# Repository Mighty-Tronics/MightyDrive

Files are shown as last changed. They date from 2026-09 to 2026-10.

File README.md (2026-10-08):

# MT Drive — Four-Channel PWM Pump Interface

**Certified Open Source Hardware — [OSHWA LU000003](https://certification.oshwa.org/lu000003.html)**

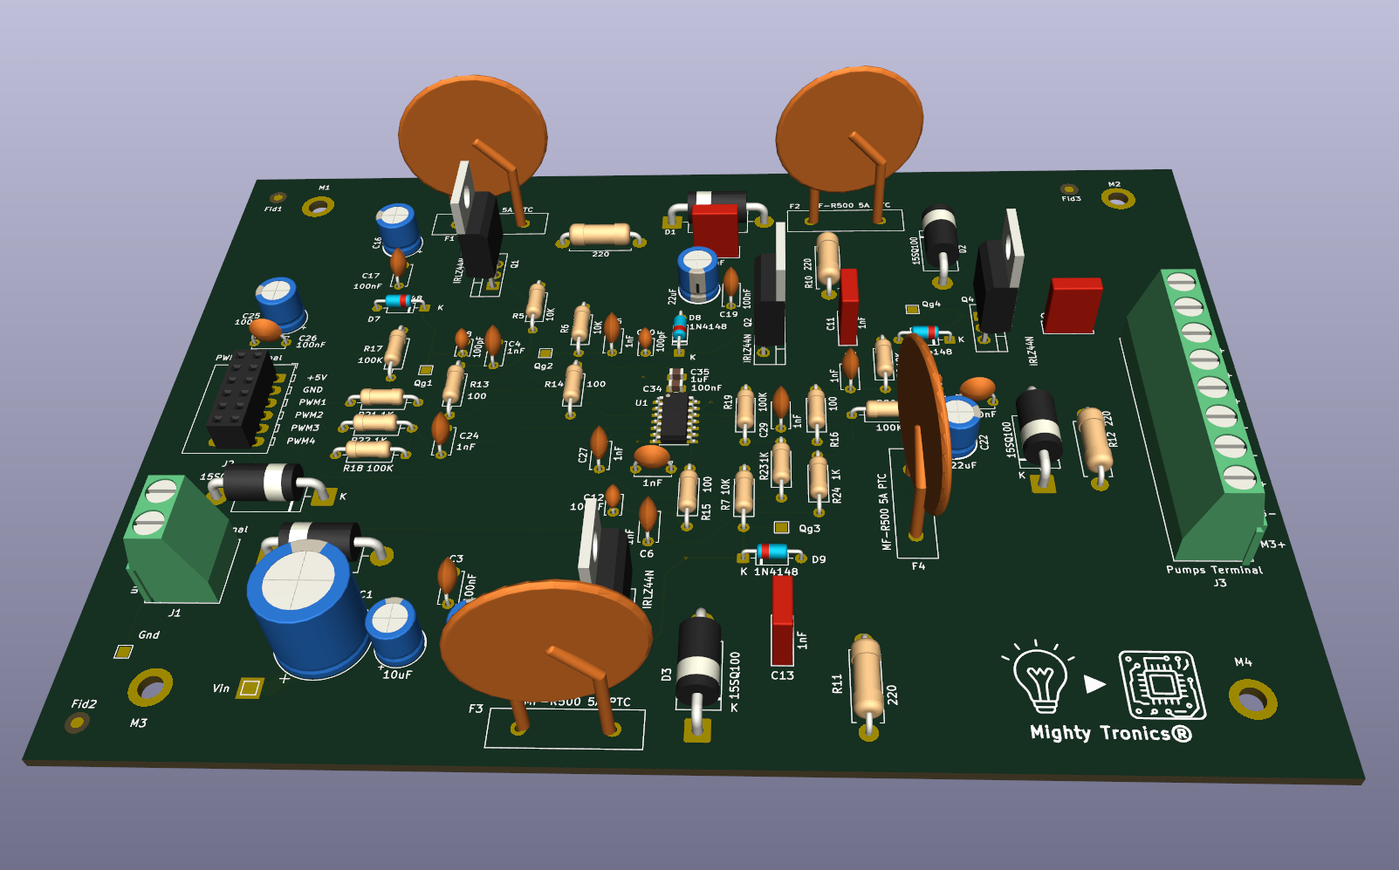
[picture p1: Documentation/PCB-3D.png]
PCB 3D


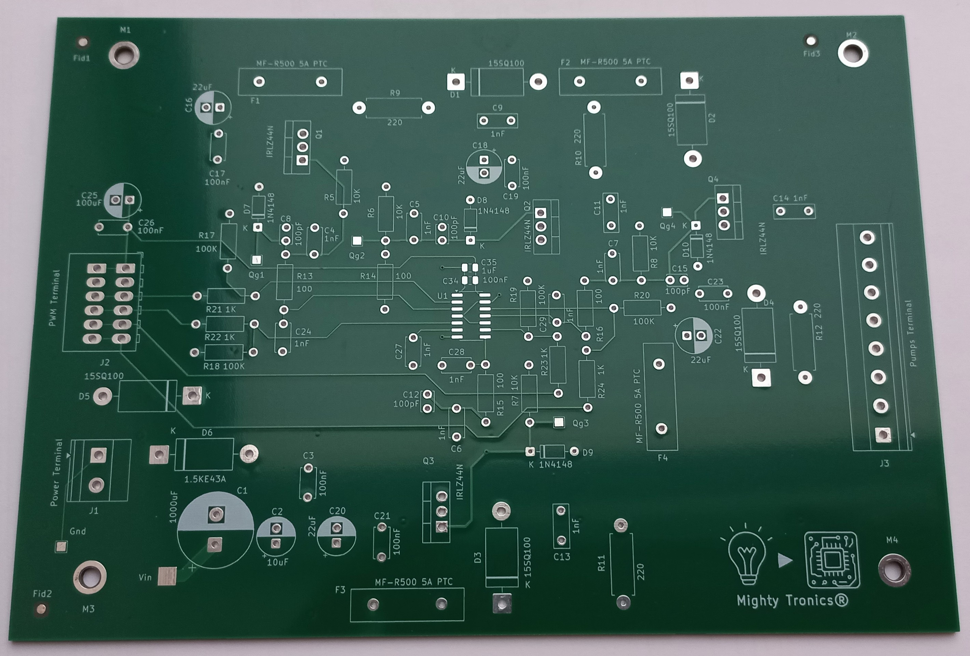
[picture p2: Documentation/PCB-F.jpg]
PCB-photo1


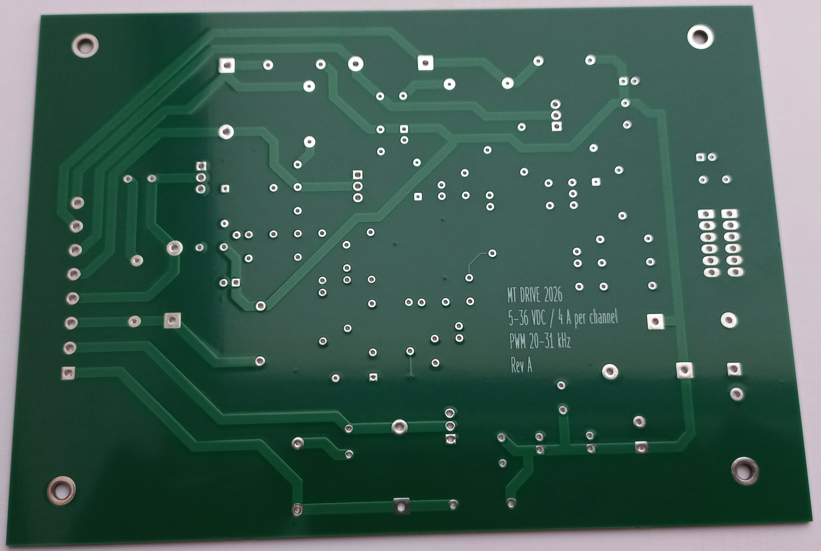
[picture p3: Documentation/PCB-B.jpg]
PCB-photo2


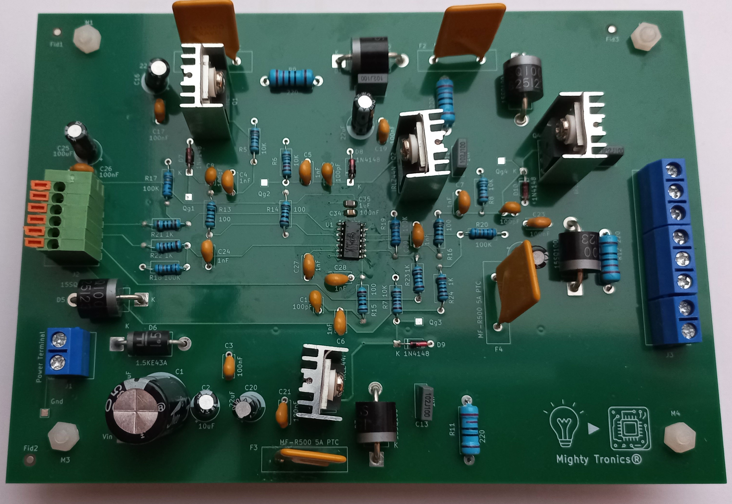
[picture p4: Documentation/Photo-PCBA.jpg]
PCBA-photo


MT Drive is an open-hardware power interface for controlling up to four brushed DC pumps or comparable inductive DC loads from an external microcontroller.

Each channel accepts an independent PWM command and switches the load through a protected low-side MOSFET stage. The microcontroller, firmware, regulated +5 V logic supply, motor supply and pumps remain external to the board.

> **Hardware status:** prototype revision V2.0, manufactured by PCBWay and under qualification.  
> **Published electrical rating:** 2 A continuous per channel, 8 A continuous total.  
> **Extended operation:** up to 3 A per channel may be characterized, but is not guaranteed for this hardware revision.

## Main specifications

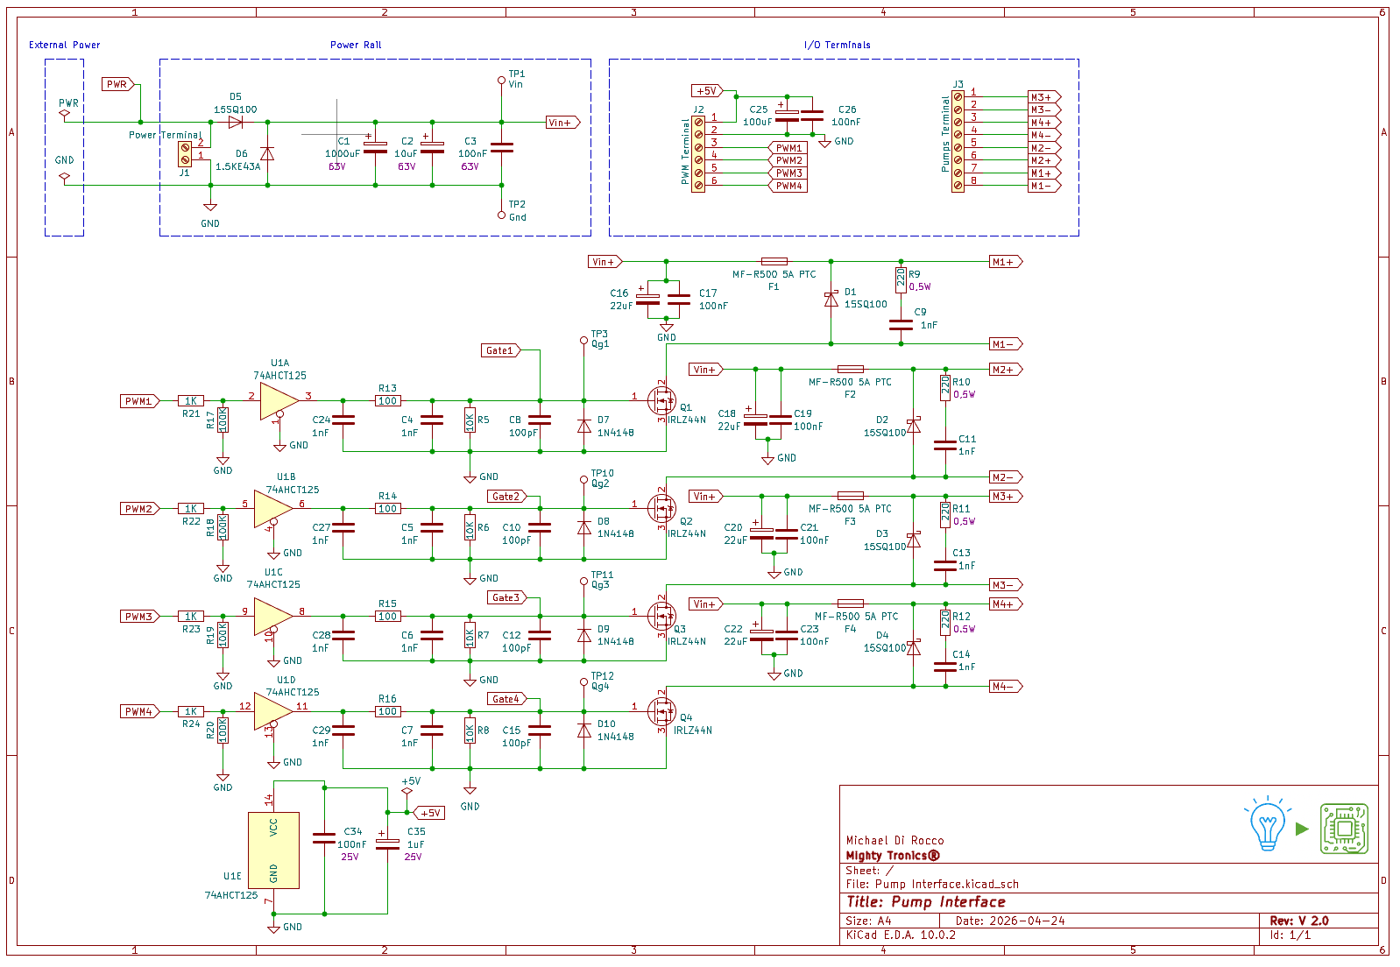
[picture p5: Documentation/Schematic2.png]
Schematic


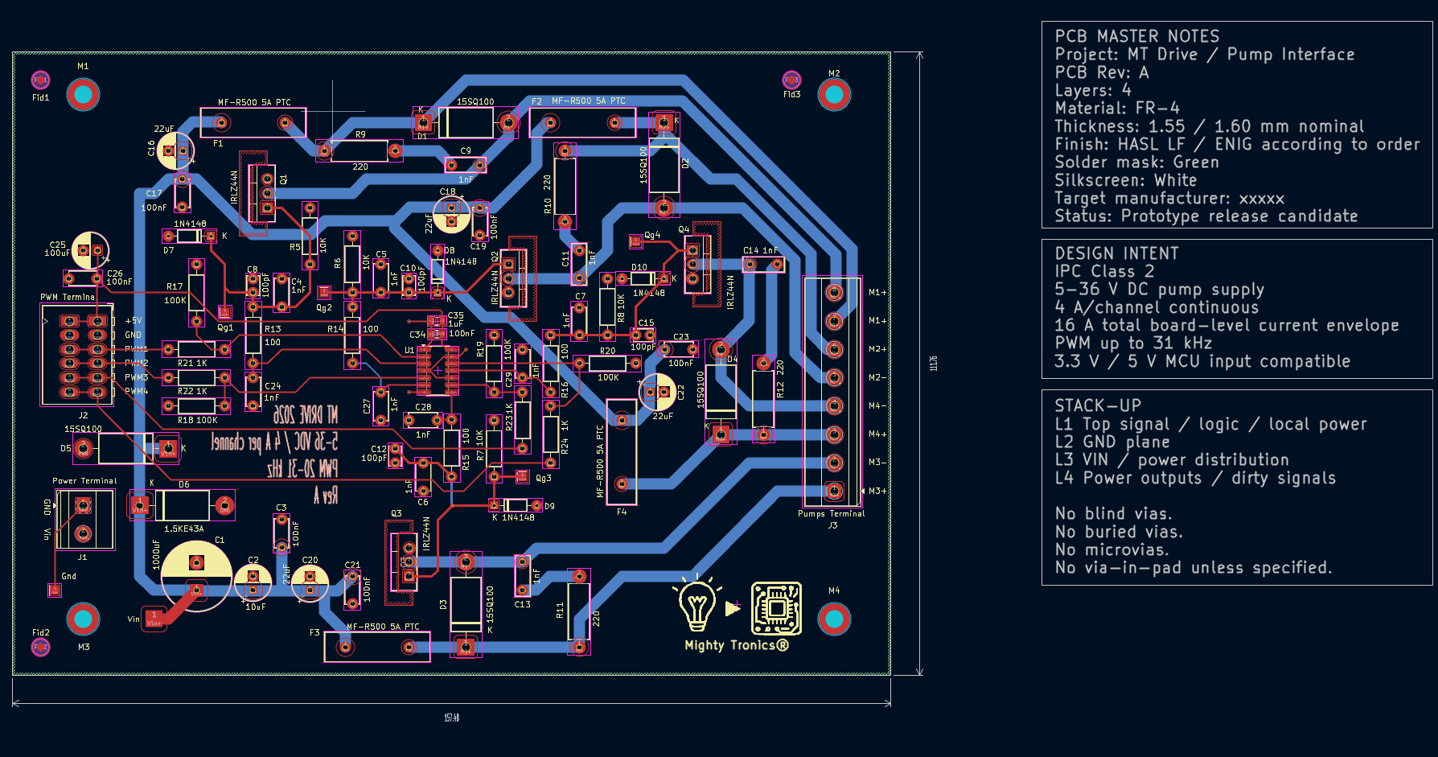
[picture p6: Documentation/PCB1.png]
PCB


| Characteristic | Published specification |
| --- | --- |
| Number of channels | 4 independent outputs |
| Motor supply | 5–36 V DC, externally supplied |
| Continuous current | 2 A maximum per channel |
| Aggregate continuous current | 8 A maximum |
| Extended characterization | Up to 3 A per channel / 12 A total, not guaranteed |
| PWM frequency | 31.5 kHz nominal |
| PWM input levels | 3.3 V or 5 V logic |
| Logic supply | Regulated +5 V external supply |
| Switching topology | N-channel MOSFET, low-side switching |
| Intended ambient range | −10 °C to +50 °C |
| Galvanic isolation | None; logic and motor power use a common ground |
| Hardware reference | Pump Interface schematic V2.0, dated 24 April 2026 |

At 36 V and the published current rating, the board can deliver up to 72 W per load and 288 W to four loads. These values are load power, not PCB dissipation.

## Functional operation

### Power entry

The motor supply enters through `J1`:

- `PWR`: positive motor supply, 5–36 V DC;
- `GND`: common power and logic reference.

The common input stage includes:

- `D5` 15SQ100 series Schottky diode for reverse-polarity protection;
- `D6` 1.5KE43A TVS diode for supply transient suppression;
- `C1` 1000 µF, `C2` 10 µF and `C3` 100 nF for rail decoupling;
- `TP1` and `TP2` for protected `Vin+` and ground measurements.

### PWM command path

Each PWM input passes through a 1 kΩ series resistor and a 100 kΩ pull-down before entering one section of the `74AHCT125` buffer. The buffer is powered from +5 V and adapts a 3.3 V or 5 V controller signal to the 5 V MOSFET gate-control network.

The `74AHCT125` has been bench-tested for this level-adaptation function. It carries gate-drive current only and does not determine the motor-current rating.

The four buffer outputs are permanently enabled because their active-low `/OE` inputs are tied to ground. Gate pull-down resistors keep the MOSFETs off when the controller is disconnected or its outputs are high-impedance.

### Load switching

When a PWM command is high, the corresponding `IRLZ44N` MOSFET turns on. Current flows from `Vin+`, through the channel PTC, through the external load connected between `Mx+` and `Mx−`, and through the MOSFET to ground.

When the MOSFET turns off, the channel flyback diode maintains a local path for the inductive load current. A 22 Ω + 1 nF series RC snubber damps high-frequency ringing across each motor output.

## Connections

### J2 — Logic and PWM

| Pin | Signal | Description |
| ---: | --- | --- |
| 1 | +5 V | External regulated logic supply |
| 2 | GND | Common controller and power-stage reference |
| 3 | PWM1 | Channel 1 command |
| 4 | PWM2 | Channel 2 command |
| 5 | PWM3 | Channel 3 command |
| 6 | PWM4 | Channel 4 command |

### J3 — Pump outputs

| Pin | Signal | Pin | Signal |
| ---: | --- | ---: | --- |
| 1 | M3+ | 2 | M3− |
| 3 | M4+ | 4 | M4− |
| 5 | M2+ | 6 | M2− |
| 7 | M1+ | 8 | M1− |

### Test points

| Test point | Signal |
| --- | --- |
| TP1 | Protected motor rail `Vin+` |
| TP2 | GND |
| TP3 | Channel 1 gate, `Qg1` |
| TP10 | Channel 2 gate, `Qg2` |
| TP11 | Channel 3 gate, `Qg3` |
| TP12 | Channel 4 gate, `Qg4` |

## Protection and reliability architecture

Each channel contains:

- one `MF-R500` resettable PTC in the positive load feed;
- one `15SQ100` flyback diode;
- local 22 µF + 100 nF supply decoupling;
- one 22 Ω / 0.5 W + 1 nF series RC snubber;
- a 10 kΩ MOSFET gate pull-down;
- a 1N4148 gate clamp and gate-conditioning capacitors.

The protections have different roles and do not replace one another. The PTC limits sustained fault energy but is not a precision current limiter. The flyback diode controls inductive current, the snubber damps local ringing, and the TVS limits disturbances reaching the common supply rail.

The 55 V `IRLZ44N` has 19 V of absolute drain-voltage headroom at a 36 V supply. The internal qualification target is a repetitive `VDS` peak no greater than 45 V under the published load, worst switching condition and longest intended motor cable.

## Current and thermal basis

The 2 A/channel rating is based on the complete current path rather than on the headline rating of a single semiconductor.

- Four channels at 2 A give an 8 A continuous common-path current.
- Using the 15SQ100 maximum forward-voltage screening value of 0.82 V gives a conservative `D5` loss bound of 6.56 W at 8 A. Actual forward drop and case temperature must be measured.
- The `MF-R500` hold current falls with ambient temperature; 2 A retains useful margin up to the declared +50 °C design ambient.
- MOSFET conduction and switching losses are verified at 31.5 kHz from measured gate and drain waveforms.
- Power-component case temperatures are checked against the 90 °C internal qualification target.

Operation above 2 A per channel, up to 3 A, is an engineering-characterization region only. It depends on duty cycle, pump start and stall current, ambient temperature, airflow, wiring, connector losses and simultaneous channel loading.

## Integration requirements

1. Connect the controller ground to `J2 GND` before applying PWM signals.
2. Apply a regulated +5 V supply to `J2`; the board does not generate this voltage.
3. Use a current-limited motor supply for first power-up.
4. Size the supply, connectors and cable loop for 8 A continuous total current plus pump start-current transients.
5. Keep PWM and ground wiring short and route motor cables away from sensitive logic wiring.
6. Do not exceed 2 A continuous on any channel or 8 A continuous in total within the published specification.
7. Verify each pump's start and stall current before qualification in the final system.

The board does not regulate motor voltage, provide active electronic current limiting or provide galvanic isolation. It is a component for integration, not a complete protected end product.

## Validation plan

The production-representative board is verified using the following sequence:

1. Inspect component orientation, solder joints and unpowered resistance paths.
2. Apply logic power only and verify all four PWM inputs, buffer outputs and MOSFET gates at 3.3 V and 5 V input levels.
3. Test each channel with a current-limited resistive load before connecting pumps.
4. Verify operation at 31.5 kHz and 10%, 50% and 90% duty cycle.
5. Qualify one channel at 36 V / 2 A over the full duty-cycle range.
6. Qualify four simultaneous channels at 36 V / 2 A per channel after thermal stabilization.
7. Measure MOSFET `VDS` peaks and ringing with the longest intended cable.
8. Record start, stall, reverse-polarity, endurance and high-ambient behaviour.
9. Characterize operation progressively above 2 A and up to 3 A separately, without changing the published rating.
10. Complete EMC pre-compliance tests using the final PCB, pumps, supply and cabling.

No CE conformity claim is made solely from this prototype or this repository. Regulatory assessment applies to the final integrated product and its intended use.

## Repository contents

The repository separates editable design sources from documentation and generated manufacturing outputs:

| Location | Contents |
| --- | --- |
| `Documentation/` | BOM in ODS and CSV formats; schematic images; drill maps; Gerber and Excellon manufacturing files in a ZIP archive; Master Drawing; functional and engineering notes. |
| `Kicad_Files/` | Native KiCad files for viewing and editing the schematic and PCB. |
| `README.md` | Project overview, specifications, integration guidance and certification information. |
| `LICENSE.md` | Project licence information. |

The native KiCad files are the authoritative editable design sources. Rendered schematics, PDFs and manufacturing files are provided for convenient review and production, but do not replace the native source files.

Every hardware release must identify its PCB revision or release date and match it to an immutable repository tag, BOM, schematic, layout and validation evidence.

[Master Drawing — Pump Interface, Rev A](https://github.com/Mighty-Tronics/MightyDrive/blob/main/Documentation/Pump_Interface_MasterDrawing_Rev_A.pdf)

## OSHWA certification

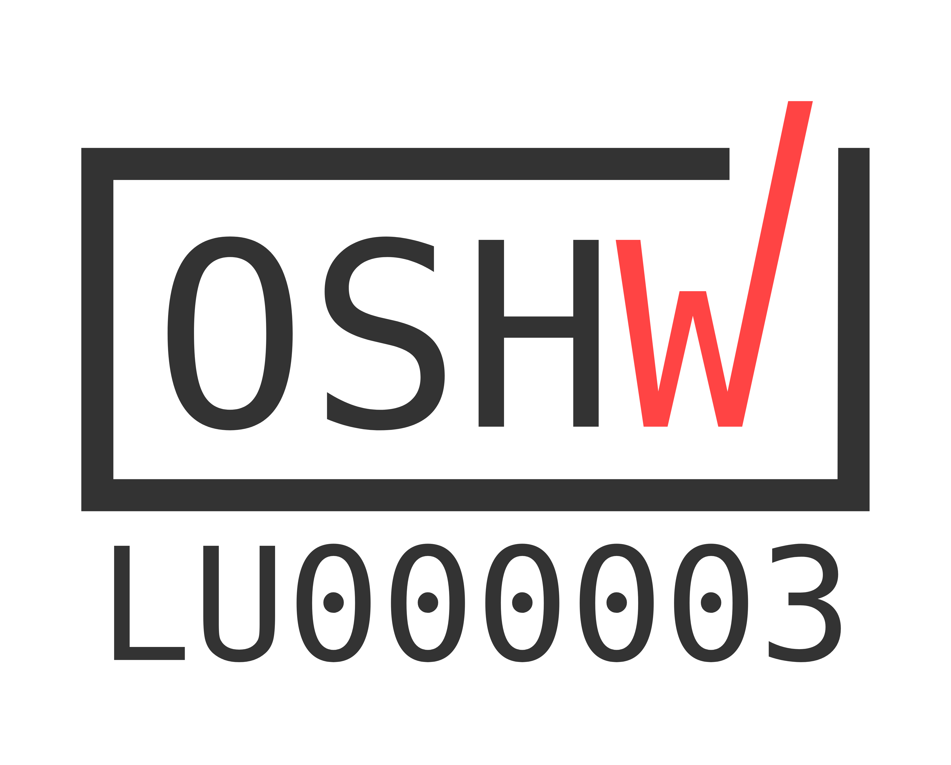
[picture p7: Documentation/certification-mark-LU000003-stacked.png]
OSHWA Certified Open Source Hardware — LU000003 (https://certification.oshwa.org/lu000003.html)


**MT Drive is certified open source hardware under the Open Source Hardware Association (OSHWA) certification program.** The project is registered as **Mighty Drive** in the official OSHWA directory.

| Certification information | Details |
| --- | --- |
| Registered project name | Mighty Drive |
| Unique identifier (UID) | **LU000003** |
| Certification date | **3 October 2026** |
| Official registration | [OSHWA project record — LU000003](https://certification.oshwa.org/lu000003.html) |

OSHWA certification identifies projects that comply with the [Open Source Hardware Definition](https://oshwa.org/definition/). The editable design files and project documentation are published so that users can study, modify, build and distribute the design under the applicable licence.

**Certification scope:** OSHWA certification concerns open-source hardware compliance. It does not certify electrical performance, product safety or CE/EMC conformity. Hardware qualification and final-system regulatory assessment are addressed separately in the validation plan above.

The certification mark and UID refer to the project covered by the official registration. Use of the mark follows the [OSHWA Certification Mark Usage Guidelines](https://certification.oshwa.org/mark-usage.html).

## License

The hardware design and original project documentation are released under the **CERN Open Hardware Licence Version 2 — Strongly Reciprocal (`CERN-OHL-S-2.0`)**. See [`LICENSE.md`](LICENSE.md) and the [official CERN-OHL-S v2 licence text](https://ohwr.org/cern_ohl_s_v2.txt) for the applicable terms.

| Project material | License |
| --- | --- |
| Hardware design, schematic, PCB, fabrication files and BOM | CERN-OHL-S-2.0 |
| Original project documentation | CERN-OHL-S-2.0 |
| Software or firmware | None included in this release |

Third-party data sheets and manufacturer files retain their owners' respective rights and are not relicensed by their inclusion or citation. The OSHWA certification mark remains subject to OSHWA's own usage terms.

## Documentation

The detailed functional description, engineering calculations, component-level implementation and qualification criteria are provided in the project documentation under [`Documentation/`](Documentation/).

## Maintainer

[info@mightytronics.eu](mailto:info@mightytronics.eu)

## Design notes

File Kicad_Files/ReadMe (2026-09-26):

This folder include all schematics and pcb files done by Kicad 10.

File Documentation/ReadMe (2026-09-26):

This folder include all necessary documents to understand the projects:
_PGN and PDF files of schematics and PCB
_Master Drawing
_BOM list
_Engineering doc

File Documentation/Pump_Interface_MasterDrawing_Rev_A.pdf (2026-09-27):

# PUMP INTERFACE MASTER

# DRAWING – REV A

Michael

info@mightytronics.eu

Version & Revision

V 1.0

## MIGHTY TRONICS®

Project name: Pump Interface | Page 1 / 12
Version : 1.0

## LIST OF CONTENTS

## 1. HISTORY OF VERSION

Date | Version | Amendments
27-09-2026 | V1.0 | Document initiation

## 2. IDENTIFICATION AND DRAWING AUTHORITY

Item | Definition
Board / design | MT Drive — Pump Interface; four-layer rigid PCB
Fabrication package | Pump Interface-GerberExcellon_Y2 (JLCPCB product detail screenshot)
Manufacturer / lot | JLCPCB / 5 individual PCBs; one design
Source CAD | Pump Interface.kicad_pcb; native board file not supplied for this revision
Data precedence | Approved fabrication data and order settings govern geometry and process. Resolve any conflict with this drawing before fabrication. Do not scale the illustration.
Drawing status | Documentation draft for the existing prototype order; not released as a new fabrication authority

## 3. BOARD OUTLINE AND REFERENCE VIEW

Property | Specified value / source
Overall dimensions | 157.5 × 111.8 mm, as displayed in the JLCPCB order detail
Outline tolerance | ±0.2 mm (Regular), as selected in the JLCPCB order
Board thickness | 1.6 mm nominal; manufacturing tolerance per JLCPCB order/process
Board construction | Four-layer FR-4, material option TG135; dielectric stack-up not separately specified
Mounting holes | 4 × Ø3.20 mm NPTH, subject to Excellon and Edge.Cuts verification

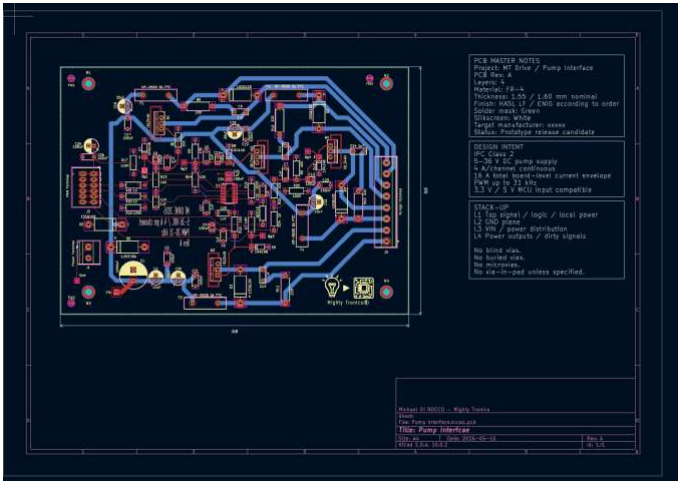
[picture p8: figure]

Figure 1 - Supplied KiCad drawing screenshot, shown for reference only. Some embedded notes reflect earlier assumptions; the verified order settings in Sections 3 and 4 take precedence. The drawing image must not be used to derive dimensions.

## 4. LAYER STRUCTURE AND ORDERED FABRICATION OPTIONS

Layer / feature | Function and order setting
L1 / F.Cu | Top copper, nominal 1 oz (approximately 35 µm copper weight equivalent); signals, logic and local power
L2 / In1.Cu | Inner copper, nominal 2 oz (approximately 70 µm); GND plane
L3 / In2.Cu | Inner copper, nominal 2 oz (approximately 70 µm); VIN / power distribution
L4 / B.Cu | Bottom copper, nominal 1 oz (approximately 35 µm); power outputs and other routed nets
Layer sequence / dielectrics | Four layers ordered; “No requirement” for a specified stack-up. Confirm actual dielectric construction with the manufacturer if controlled impedance or dielectric spacing is required.
Surface finish | HASL with lead (SnPb), as ordered. Do not label this finish lead-free.
Solder mask / legend | Green solder mask; white ink-jet silkscreen
Via treatment | Covered vias (“Bouché” in the translated order detail); confirm the exact JLCPCB process meaning from production data if plugging/filling is required
Electrical test | Full flying-probe electrical test
Appearance quality | JLCPCB “IPC Class 2 Standard” option; not independent evidence of full IPC-6012 certification
Other selections | No castellations, blind holes, edge plating, countersinks, gold fingers, UL marking or inspection report ordered

Copper weights describe the manufacturer order selections. The approximate 35/70 µm conversions are nominal copper-weight equivalents, not measured final thicknesses or guaranteed finished copper tolerances. External plating may affect local finished thickness.

## 5. DRILL SCHEDULE

Tool | Hole type | Nominal Ø | Count | Plated
T1 | PTH | 0.40 | 4 | Yes
T2 | PTH | 0.65 | 8 | Yes
T3 | PTH | 0.80 | 84 | Yes
T4 | PTH | 0.90 | 12 | Yes
T5 | PTH | 1.00 | 10 | Yes
T6 | PTH | 1.20 | 12 | Yes
T7 | PTH | 1.25 | 2 | Yes
T8 | PTH | 1.30 | 12 | Yes
T9 | PTH | 1.40 | 20 | Yes
T10 | NPTH | 3.20 | 4 | No

Schedule total: 164 plated through holes and 4 non-plated through holes, 168 holes overall. Verify the schedule against the final Excellon files. Confirm whether the workbook numbers represent required finished hole diameters or nominal drill tool sizes; these conventions must not be mixed.

## 6. GENERAL FABRICATION NOTES

- Fabricate to the approved four-copper-layer Gerber data, plated and non-plated Excellon files, Edge.Cuts profile, and manufacturer order settings. Query any discrepancy before manufacture.
- The manufacturer order specifies 1 oz outer and 2 oz inner copper. The 2 oz selection applies to BOTH L2 and L3, not only to the power plane.
- Provide plated through holes for T1–T9 and non-plated mounting holes for T10, after drill-file reconciliation. No blind or buried vias or microvias are specified.
- Apply solder mask and silkscreen as defined by the fabrication data; maintain legible reference markings and keep ink off exposed solderable pads.
- The PCB is supplied as individual boards, without panelization. Component placement, polarity and soldering acceptance belong to a separate assembly drawing and inspection plan.
- Do not infer electrical current rating from copper weight alone. The product positioning is 2 A continuous per channel, 8 A total guaranteed; operation up to 3 A per channel may be possible but is not guaranteed. This is a product performance statement requiring validation, not a bare-board acceptance criterion.

## 7. ENGINEERING RELEASE CHECKS

ID | Required disposition before releasing a new fabrication revision
R-01 | Compare native .kicad_pcb outline, actual layer assignments, copper pours, and dimension annotations with the 157.5 × 111.8 mm ordered dimensions and the final Gerbers.
R-02 | Reconcile every Excellon tool, count and PTH/NPTH classification against Section 4. Confirm finished-hole versus drill-size convention.
R-03 | Check MOSFET TO-220 footprint and real lead geometry: the workbook lists a 1.20 mm hole while its calculated lead envelope reaches 1.43 mm. The workbook “OK” flag does not resolve this discrepancy.
R-04 | Resolve overlapping/ambiguous component reference groupings in the hole-to-component table, including C3. Check against the BOM and PCB footprints.
R-05 | Run PCB DRC and review the plotted Gerbers and Excellon in GerbView and in the JLCPCB preview. Record exceptions and archive the approved upload package.
R-06 | If RoHS/lead-free assembly is intended, resolve the ordered HASL-with-lead finish and document an appropriate surface finish for a future revision.

## 8. DESIGN DOCUMENTATION AND KICAD EXPORTS

The purpose of the following exports is to document the design and support test results, review, and future revisions.

8.1. PRESERVE THE MANUFACTURED REVISION

Archive the exact Pump Interface-GerberExcellon_Y2 package submitted to JLCPCB, together with the corresponding native KiCad project files and the JLCPCB order details. Identify this package as the manufactured revision. If the KiCad board has since been modified, label the current files separately; newly generated exports must not be presented as the files used to manufacture this lot.

8.2. REQUIRED DOCUMENTATION EXPORTS
Document or data | Purpose
Schematic PDF | Records circuit connections, component references, values, and interface names
PCB overview PDF | Provides a readable overall view for the design and test file
Copper layer PDFs | Records routing and the two internal planes for engineering review
Fabrication and outline PDF | Records the board profile, mounting features, and fabrication annotations
Drill map and drill report | Supports verification of hole locations, tool diameters, and PTH/NPTH separation against the hole-control spreadsheet
DRC report | Records the design-rule status of the archived KiCad revision; document any accepted exceptions

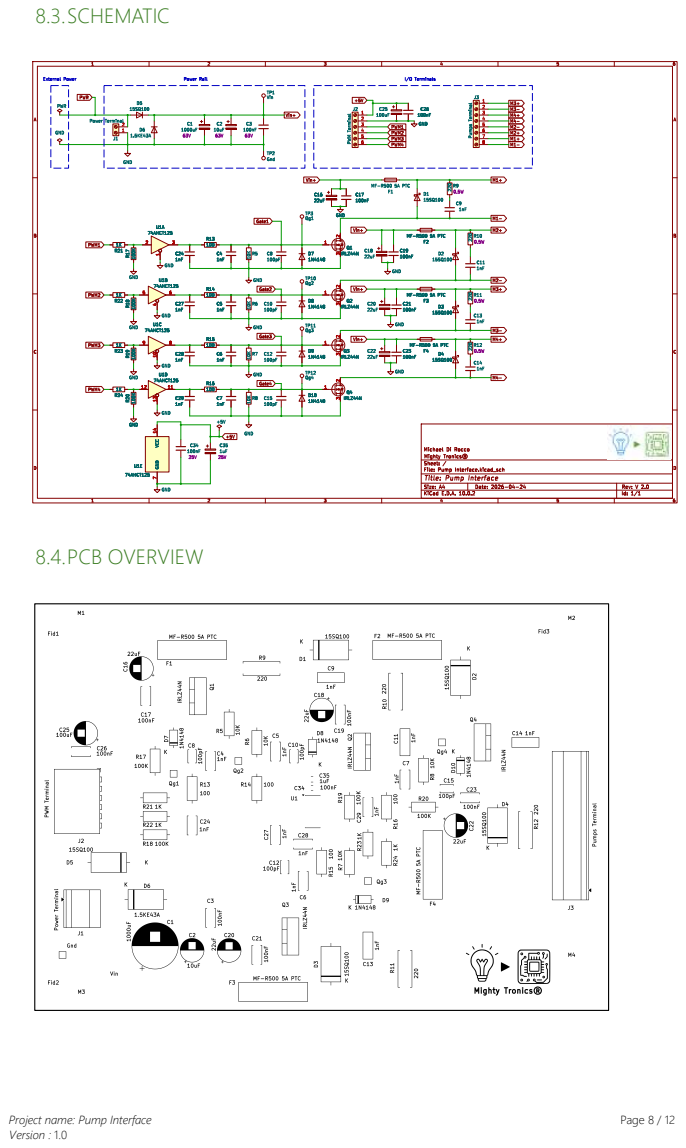
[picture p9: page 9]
8.3.SCHEMATIC; 8.4.PCB OVERVIEW

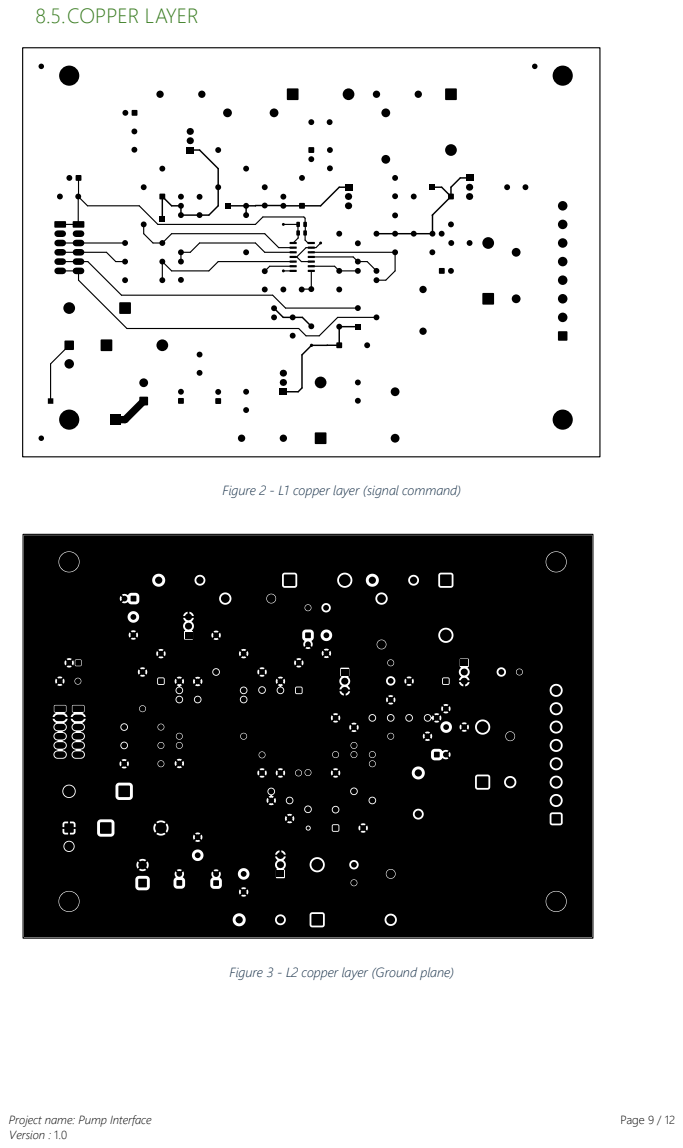
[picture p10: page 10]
8.5.COPPER LAYER

Figure 2 - L1 copper layer (signal command)

Figure 3 - L2 copper layer (Ground plane)

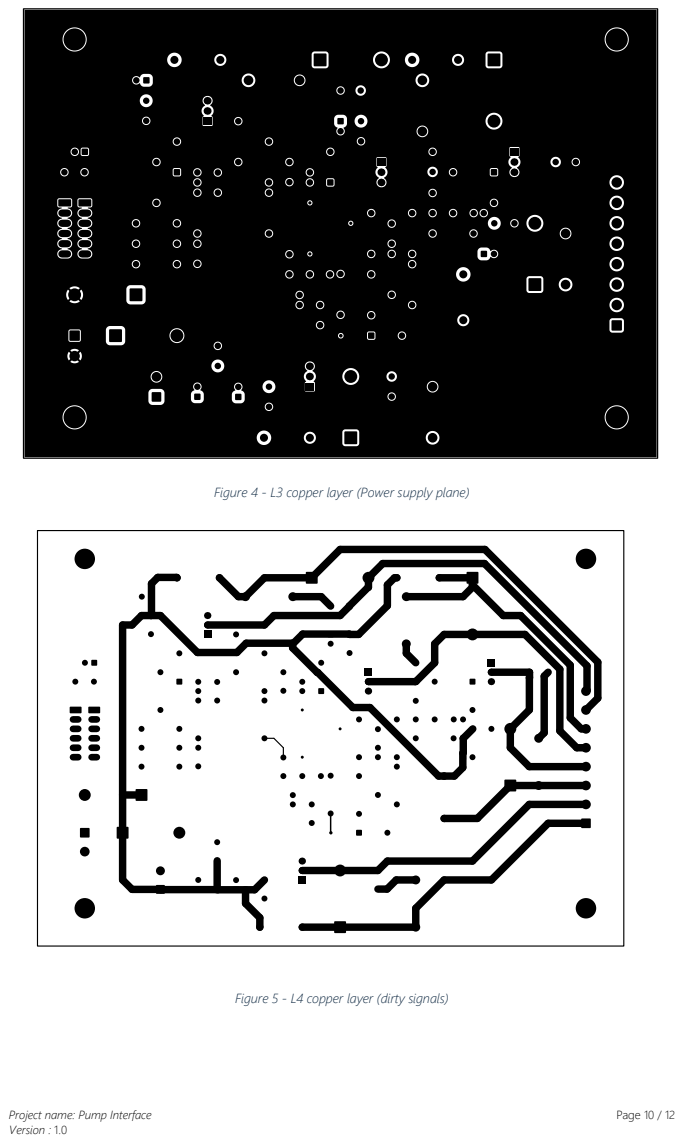
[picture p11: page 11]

Figure 4 - L3 copper layer (Power supply plane)

Figure 5 - L4 copper layer (dirty signals)

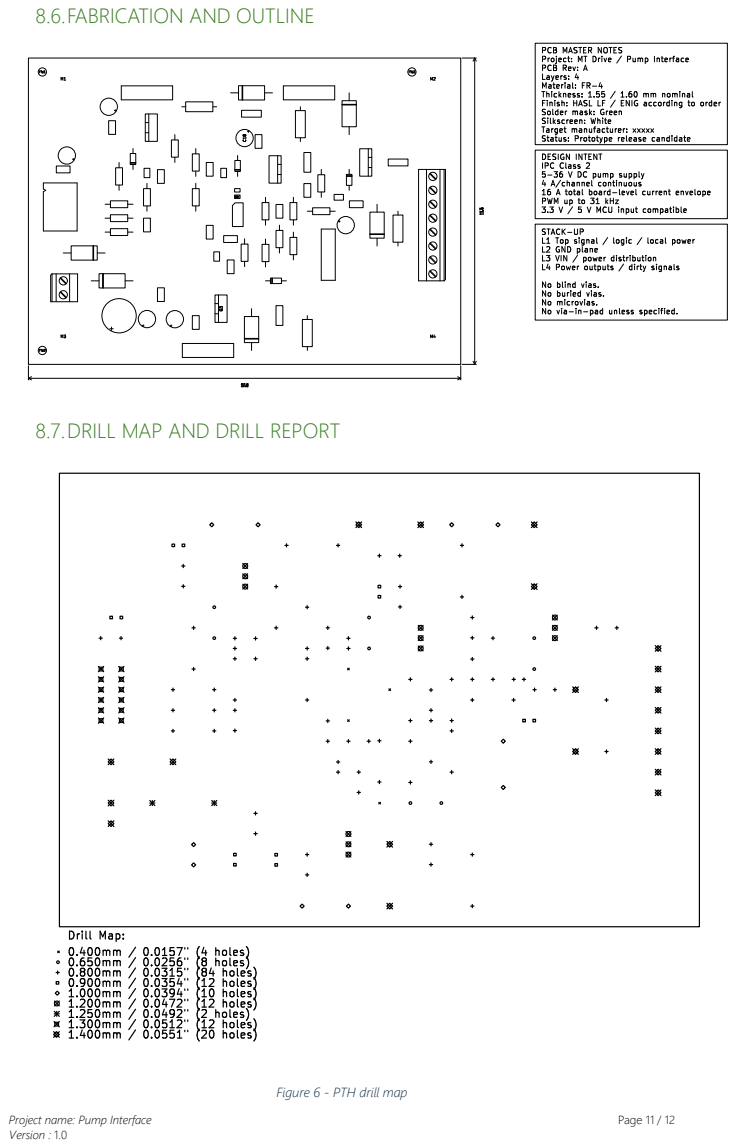
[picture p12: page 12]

8.6.FABRICATION AND OUTLINE

8.7.DRILL MAP AND DRILL REPORT

Figure 6 - PTH drill map

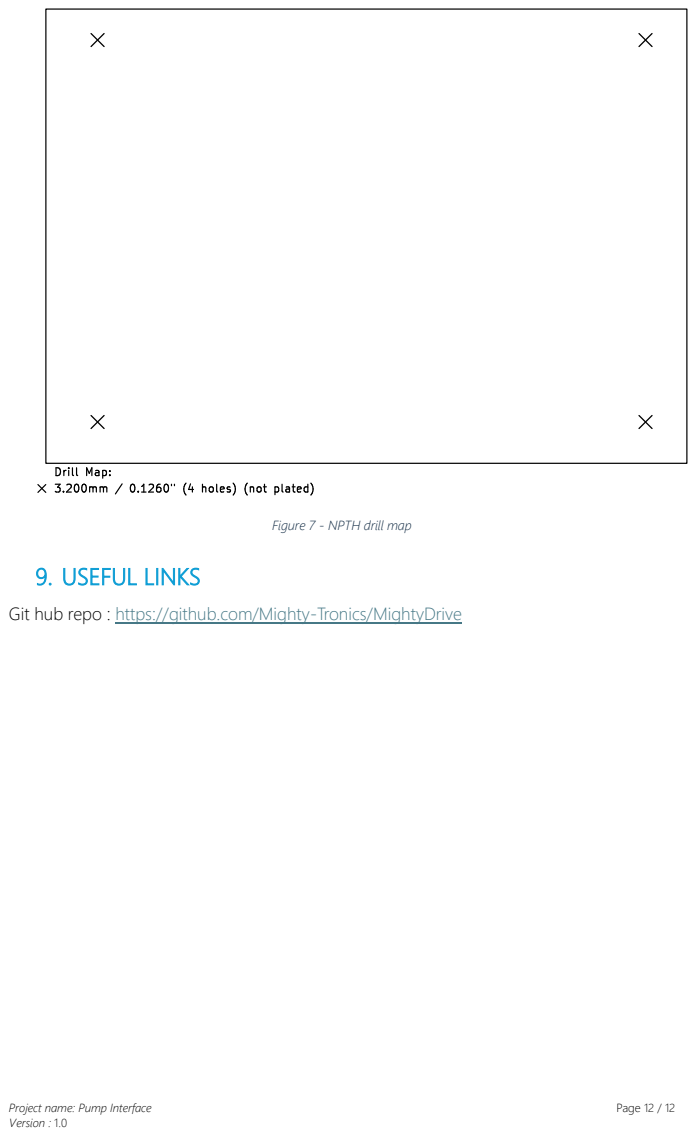
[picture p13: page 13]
9. USEFUL LINKS

Figure 7 - NPTH drill map

Git hub repo : https://github.com/Mighty-Tronics/MightyDrive

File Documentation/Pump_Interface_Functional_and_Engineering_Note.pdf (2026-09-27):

# PUMP INTERFACE

# FUNCTIONAL &

# ENGINEERING NOTE

Michael

info@mightytronics.eu

Version & Revision

V 2.0

## MIGHTY TRONICS®

Project name: Pump Interface | Page 1 / 13
Version : 2.0

## LIST OF CONTENTS

## 1. HISTORY OF VERSION

Date | Version | Amendments
26-09-2026 | V1.0 | Document initiation.
27-09-2026 | V 2.0 | Revise doc to adapt for 2A max by
| | channel to ensure safety and quality.

## 2. PURPOSE AND SCOPE

2.1. WHY THIS DOCUMENT?

This document describes what the four-channel MT Drive board does, how it is connected and how the implemented circuit operates. It then records the component choices, electrical calculations, qualification criteria and publication elements needed to reproduce and maintain the hardware.

2.2.PUPOSE ANS SCOPE OF MT DRIVE

MT Drive is a four-channel interface for controlling brushed DC pumps or comparable inductive DC loads from a microcontroller. Each load is switched independently by PWM. The board does not generate the PWM signals, regulate the motor supply or provide galvanic isolation.

This description applies to the schematic titled “Pump Interface”, hardware revision V2.0 dated 24 April 2026. The published operating rating is separated from the extended characterization region so that the guaranteed capability remains unambiguous.

## 3. DECLARED OPERATING ENVELOPE

Published rating: 2 A continuous per channel and 8 A continuous total, from a 5 to 36 V DC motor supply.

Operation up to 3 A per channel may be evaluated, but it is not guaranteed for this hardware revision.

Characteristic | Published specification | Extended characterization
Motor supply | 5 to 36 V DC | 5 to 36 V DC
Channels | 4 independent low-side outputs | Same architecture
Continuous load current | 2 A maximum per channel | Up to 3 A per channel, not guaranteed
Aggregate continuous current | 8 A maximum | Up to 12 A, not guaranteed
PWM frequency | 31.5 kHz nominal | 31.5 kHz nominal
Logic supply | +5 V external | +5 V external
PWM input levels | 3.3 V or 5 V logic | Same interface
Design ambient | −10 °C to +50 °C | Requires separate characterization

## 4. FUNCTIONAL OPERATION

Please refer to chapter 16 of this document for the schematic.

4.1. POWER-UP AND IDLE STATE

The motor supply enters through J1. Series diode D5 blocks a reverse-polarity connection. TVS diode D6 and capacitors C1, C2 and C3 limit supply disturbances and provide local energy storage. The protected rail is labelled Vin+ and is available at TP1; TP2 is the power ground reference.

The control electronics receive a separate +5 V supply through J2. The controller ground and the board ground must be connected. Pull-down resistors hold the four PWM inputs and the four MOSFET gates low when the controller is disconnected or its outputs are high-impedance. The default state is therefore all loads off.

4.2.COMMAND AND LOAD ENERGIZATION

A logic-high PWM command is accepted by one section of U1, a 74AHCT125 powered from +5 V. The AHCT input threshold allows a 3.3 V controller signal to be translated to a 5 V logic output. The output then drives the corresponding IRLZ44N gate through the conditioning network.

When the MOSFET is on, current flows from Vin+ through the channel PTC, through the external load connected between Mx+ and Mx−, and through the MOSFET to ground. The load therefore sees the motor-supply voltage during the PWM on-time. The average delivered energy follows the commanded duty cycle.

4.3.TURN-OFF AND INDUCTIVE-CURRENT PATH

When the MOSFET turns off, the current of an inductive load cannot stop instantaneously. The channel flyback diode provides a local recirculation path from Mx− back to Mx+. The resistor 22 Ω + capacitor 1 nF series RC network (snubber) across the output pair damps high-frequency ringing. The input TVS limits residual transients that reach the common supply rail.

4.4.PROTECTION BEHAVIOUR

Each branch includes an MF-R500 resettable fuse. It limits sustained fault energy by increasing resistance as it heats; it is not a precision electronic current limiter. D5 protects against reversed input polarity, D6 clamps supply transients, the flyback diodes control inductive current, and the gate diodes limit negative gate excursions. These functions are complementary.

## 5. EXTERNAL INTERFACES

Interface | Connection | Function and requirement
J1 | PWR, GND | Motor supply input, 5 to 36 V DC. The source and wiring must support the total load current.
J2 pin 1 | +5 V | External regulated logic supply for U1; this voltage is not generated on the board.
J2 pin 2 | GND | Common reference for the logic supply, PWM source and motor power stage.
J2 pins 3–6 | PWM1–PWM4 | Independent 3.3 V or 5 V logic commands, 31.5 kHz nominal.
J3 pins 1–8 | M3+, M3−, M4+, M4−, M2+, M2−, M1+, M1− | Four two-wire load connections in the physical connector order shown.
TP1 / TP2 | Vin+ / GND | Protected motor-rail and ground measurement points.
TP3 / TP10 / TP11 / TP12 | Qg1 / Qg2 / Qg3 / Qg4 | Gate-waveform test points for channels 1 to 4 respectively.

Integration rules:

- Connect the controller ground to J2 GND before applying PWM signals.
- Apply a regulated +5 V logic supply to J2; do not rely on the motor supply to power U1.
- Use a current-limited motor supply during first power-up and begin with the loads disconnected.
- Size the supply, connector and cable loop for 8 A continuous aggregate current, plus the pump start-current transient.
- Keep PWM and ground wiring short and route motor cables away from sensitive logic or measurement wiring.
- Do not exceed 2 A continuous on any channel or 8 A continuous in total within the published rating.

## 6. FUNCTIONAL DESCRIPTION

Block | Purpose | Implemented circuit
PF1 | Power entry and distribution | J1, D5, D6, C1–C3, Vin+ rail and power-ground return.
PF2 | Four load switches | Q1–Q4 with one PTC-protected high-side feed per channel.
PF3 | Logic adaptation | U1 74AHCT125 and four input/gate-conditioning networks.
PF4 | Inductive-load protection | D1–D4 flyback diodes, R9–R12/C9–C14 snubbers and rail TVS.
PF5 | Connection and measurement | J1–J3, TP1–TP3 and TP10–TP12.

## 7. TECHNICAL IMPLEMENTATION

7.1. COMMON POWER PATH

D5 is a 15SQ100 Schottky diode in series with the positive input. D6 is a 1.5KE43A TVS connected across the protected rail. C1 = 1000 µF, C2 = 10 µF and C3 = 100 nF provide bulk, intermediate and high-frequency decoupling. Because D5 carries the sum of all channel currents, its forward drop and thermal path are common-path design limits.

7.2.LOGIC AND GATE-DRIVE PATH

Each PWM input uses a 1 kΩ series resistor and a 100 kΩ pull-down before U1. All four active-low output-enable inputs of the 74AHCT125 are tied low, so the four buffers remain enabled. U1 is decoupled by C34 = 100 nF and C35 = 1 µF.

Each buffer output drives a 100 Ω gate resistor. The implemented network also includes 1 nF shunt capacitors, a 10 kΩ gate pull-down, a 100 pF gate-source capacitor and a 1N4148 gate clamp. The 74AHCT125 has been bench-tested for the intended 3.3 V-to-5 V signal adaptation. It carries only gate-drive current and does not set the motor-current rating.

7.3.REPEATED POWER CHANNEL

Q1–Q4 are IRLZ44N N-channel MOSFETs used as low-side switches. Each channel contains an MF-R500 PTC in the positive load feed, 22 µF + 100 nF local rail decoupling, a 15SQ100 flyback diode and a 22 Ω / 0.5 W resistor in series with a 1 nF snubber capacitor across the output pair. The four channels are electrically equivalent apart from their reference designators and connector positions.

7.4.PWM TIMING

T = 1 / 31,500 = 31.75 µs PWM period

tON = 15.87 µs at 50% duty cycle nominal half-period

The gate waveform must reach stable low and high levels within each PWM period. Duty-cycle preservation is verified at the PWM input, buffer output, MOSFET gate and switched output.

## 8. ELECTRICAL DIMENSIONING

8.1. PUBLISHED CURRENT AND LOAD POWER

I_total = 4 × 2 A = 8 A

P_channel,max = 36 V × 2 A = 72 W

P_load,max = 36 V × 8 A = 288 W

The 288 W value is the maximum electrical power delivered to the four external loads. It is not the heat dissipated by the PCB. PCB dissipation is determined by semiconductor voltage drops, conductor resistance, switching losses and connector losses.

8.2.EXTENDED, NON-GUARANTEED REGION

I_total,extended = 4 × 3 A = 12 A

P_load,extended = 36 V × 12 A = 432 W

These values define the upper characterization region only. They shall not appear as a guaranteed product rating, and operation in this region does not relax the thermal, voltage or protection limits of any component.

8.3.MOSFET CONDUCTION LOSS

The IRLZ44N data sheet specifies a maximum on-state resistance of 46 mΩ at VGS = 4 V and 25 °C. For thermal screening, 80 mΩ is used as a conservative hot-state design value. Full-duty operation is the worst case for conduction loss.

Pcond = I² × RDS(on) × D D is the PWM duty cycle

Operating point | RDS(on) basis | Loss per channel | Four-channel total
2 A guaranteed, 25 °C basis | 46 mΩ | 0.184 W | 0.736 W
2 A guaranteed, hot design basis | 80 mΩ | 0.320 W | 1.280 W
3 A extended, 25 °C basis | 46 mΩ | 0.414 W | 1.656 W
3 A extended, hot design basis | 80 mΩ | 0.720 W | 2.880 W

8.4.MOSFET SWITCHING LOSS

Psw = 0.5 × VDS × ID × (tr + tf) × fPWM

At 36 V, 2 A and 31.5 kHz, every 100 ns of combined rise and fall time contributes approximately 0.113 W per channel. At 3 A, the same 100 ns contributes approximately 0.170 W per channel. The final value shall use oscilloscope measurements taken directly at the gate and drain on the assembled board.

Current | Switching-loss coefficient | Example at tr + tf = 200 ns | Example at tr + tf = 500 ns
2 A | 0.113 W per 100 ns | 0.227 W | 0.567 W
3 A extended | 0.170 W per 100 ns | 0.340 W | 0.851 W

Total MOSFET loss is the sum of conduction and switching losses. Gate-drive loss, ringing and avalanche energy are assessed separately during prototype validation.

## 9. CURRENT-PATH AND THERMAL MARGINS

9.1. COMMON REVERSE-POLARITY DIODE

The common 15SQ100 diode carries the aggregate motor current. The manufacturer specifies 15 A average forward current and a maximum forward voltage of 0.82 V at the stated test point. Using 0.82 V provides a conservative thermal screening bound rather than a prediction of the actual operating voltage drop.

Mode | Aggregate current | Screening calculation | Engineering interpretation
Guaranteed | 8 A | 8 A × 0.82 V = 6.56 W | Thermal qualification required; copper around the diode is a design-critical heat path.
Extended | 12 A | 12 A × 0.82 V = 9.84 W | High thermal stress; operation is not guaranteed.

The acceptance decision shall use the measured forward drop and stabilized case temperature at 8 A total. The nameplate current alone is not sufficient to establish the board rating.

9.2.CHANNEL PTC MARGIN

Each channel uses an MF-R500 resettable fuse. Its hold current decreases with ambient temperature. The 2 A rating maintains useful margin over the declared −10 °C to +50 °C design range. The PTC is a fault-energy limiter; its hold current must not be interpreted as the board's guaranteed load rating.

Ambient temperature | MF-R500 hold current | Margin at 2 A | Margin at 3 A
23 °C | 5.00 A | 2.50× | 1.67×
40 °C | 4.15 A | 2.08× | 1.38×
50 °C | 3.85 A | 1.93× | 1.28×

9.3.COPPER-PATH CALCULATION

For a representative 100 mm conductor segment, 2.0 mm wide and 70 µm thick, the calculated resistance at 20 °C is 12.3 mΩ. This normalized segment is used to compare current levels; release approval shall be based on the actual CAD current paths, neck-downs, vias and connector footprints.

Current through segment | Voltage drop | Copper loss | Use
2 A | 24.6 mV | 0.049 W | Guaranteed branch current
3 A | 36.9 mV | 0.111 W | Extended branch current
8 A | 98.4 mV | 0.787 W | Guaranteed aggregate current if geometry were identical
12 A | 147.6 mV | 1.771 W | Extended aggregate current if geometry were identical

The common power path must use substantially more copper than a single branch and shall be checked as a complete loop, including the return path.

## 10.INDUCTIVE SWITCHING AND VOLTAGE MARGIN

The flyback diode, RC snubber and supply TVS have distinct functions. The flyback diode maintains motor-current continuity, the 22 Ω + 1 nF snubber damps local ringing, and the TVS limits supply-rail transients. None of these functions replaces the others.

At a 36 V supply, the 55 V IRLZ44N has 19 V of absolute drain-voltage headroom. The internal reliability target is therefore a measured repetitive VDS peak no greater than 45 V under the guaranteed load, longest intended cable and worst switching condition. Any result above this target requires snubber adjustment, loop-layout correction or a higher-voltage MOSFET in the next revision.

The implemented snubber value is 22 Ω + 1 nF. It shall be confirmed on the assembled board from measured waveforms at 31.5 kHz and with the longest intended motor cable.

## 11. VERIFICATION AND QUALIFICATION

The guaranteed rating becomes releasable only after the following evidence is recorded on the production-representative prototype.

ID | Verification | Test condition | Acceptance criterion
QV-01 | Four-channel logic | 3.3 V and 5 V input; 31.5 kHz; 10%, 50%, 90% duty | All channels reproduce logic levels and duty cycle without abnormal distortion.
QV-02 | Single-channel power | 36 V, 2 A, 0% to 100% duty | Stable operation; no unintended turn-on or oscillation.
QV-03 | Full guaranteed load | 36 V, 2 A per channel, four channels, two-hour thermal stabilization | 8 A continuous operation without protection trip or degradation.
QV-04 | High ambient | Guaranteed load at 50 °C ambient | Power-component case temperatures remain within the 90 °C internal target.
QV-05 | Switching stress | Longest intended harness; synchronized and phase-shifted PWM | Repetitive VDS peak ≤ 45 V; no uncontrolled ringing.
QV-06 | Start and stall | Representative pumps and supply | No permanent damage; currents and PTC behaviour documented.
QV-07 | Endurance | 24 h at guaranteed envelope with duty-cycle changes | No drift, damage, connector discoloration or functional interruption.
QV-08 | Extended characterization | Progressive tests above 2 A up to 3 A per channel | Results documented as engineering data only; no guarantee created.
QV-09 | EMC pre-compliance | Final PCB, pumps, supply and cables | Emissions and immunity results recorded against the project test plan.

## 12.ASSEMBLY AND FIRST POWER-UP

- Verify part orientation for D1–D6, Q1–Q4 and polarized capacitors before applying power.
- Inspect all SMD and through-hole solder joints on the released PCB and check that no adjacent gate or output nets are bridged.
- With power removed, check resistance from Vin+ to GND and from each Mx− output to GND. A continuity-tester beep alone is not a short-circuit diagnosis because semiconductor junctions and pull-down networks create measurable paths.
- Apply +5 V logic power first with a current limit and no motor supply. Confirm U1 supply, low idle gates and a clean 0–5 V gate response on all four channels.
- Apply a low motor voltage with one current-limited resistive load, then repeat channel by channel before connecting pumps.
- Increase voltage and current progressively while recording D5, PTC, MOSFET and connector temperatures.

## 13.SAFETY, LIMITATIONS AND USE CONDITIONS

- The board is a component for integration, not a complete protected end product.
- There is no galvanic isolation between logic ground and motor-power ground.
- The board does not regulate motor voltage and does not actively limit channel current.
- The integrating system must provide a correctly rated external supply, wiring protection, enclosure, strain relief and emergency-disconnect strategy where required.
- Pump stall and start currents must be verified against the 2 A continuous rating and the measured transient response.
- Operation up to 3 A per channel is characterization only and creates no guaranteed operating entitlement.

## 14.OPEN HARDWARE RELEASE PACKAGE

This document supports an open hardware release but does not by itself establish OSHWA certification. The public repository must identify the exact hardware version and provide the editable design sources needed to study, modify and reproduce it.

Repository content | Minimum published material | Release status
Hardware source | Native KiCad project, schematic and PCB layout files for the released version. | Required
Manufacturing | Gerbers, drill files, fabrication notes, assembly drawings and pick-and-place data where applicable. | Required for reproduction
Bill of materials | Reference, quantity, value, package, manufacturer and orderable part number. | Required
Documentation | This description, schematic PDF, connector pinout, assembly guidance and validation records. | Required
License | An OSHWA-compatible hardware license applied to the hardware sources; an open license applied to documentation. | Select before certification
Version traceability | PCB marking or release date matched to an immutable repository tag and its documentation. | Required
Certification mark | Use only after OSHWA approval and assignment of a project UID. | Not applicable before approval

## 15.REFERENCES

1. Mighty Tronics, Pump Interface schematic, hardware revision V2.0, 24 April 2026.
2. Infineon Technologies, IRLZ44N HEXFET Power MOSFET data sheet.
3. Bourns, MF-R Series PTC Resettable Fuses data sheet.
4. Rectron, 15SQ100 Schottky Barrier Rectifier data sheet.
5. Nexperia, 74AHC125 and 74AHCT125 Quad Buffer and Line Driver data sheet.
6. Open Source Hardware Association, Open Source Hardware Definition, https://oshwa.org/definition/.
7. Open Source Hardware Association, Certification Requirements, https://certification.oshwa.org/requirements.html.
8. Open Source Hardware Association, Certification Process — Documentation and Hardware, https://certification.oshwa.org/process/.

## 16.APPENDIX A - RELEASED SCHEMATIC

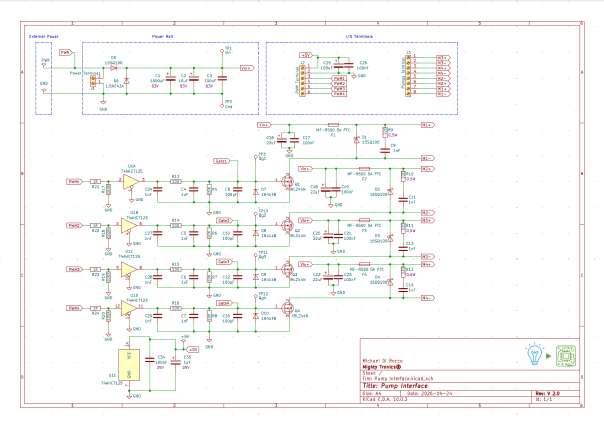
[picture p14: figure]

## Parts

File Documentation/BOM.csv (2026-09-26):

MTDrive — bill of materials, schematic V2.0
All components THT except U1, C34 and C35. Suggested footprints require PCB confirmation.
References | Qty | Value | Function / location | Technology / specification | Mount | Package / footprint to confirm | Voltage rating (V) | Power rating (W) | Manufacturer P/N | Supplier P/N | Status / engineering check | Review priorities
C1 | 1 | 1000 uF | Main DC bus | Aluminium electrolytic, ripple/ESR specified | THT | Radial; size and pitch TBD | 100 |  |  |  | Existing 63 V marking to revise; verify surge and physical fit | D5 | Thermal dissipation in 12 A common input
C2 | 1 | 10 uF | Main DC bus | Aluminium electrolytic | THT | Radial; size and pitch TBD | 100 |  |  |  | Existing 63 V marking to revise | R9-R12 | 220 ohm in supplied schematic; confirm actual build
C3 | 1 | 100 nF | Main DC bus | Ceramic X7R; effective capacitance at 36 V | THT | Radial disc; pitch TBD | 100 |  |  |  | Existing 63 V marking to revise | U1 | 74AHCT125 versus 74HCT125 identification
C4-C7 | 4 | 1 nF | Gate network | Ceramic C0G/NP0 | THT | Radial disc; pitch TBD | 50 |  |  |  | Confirm exact gate-source voltage | PCB | Verify all proposed footprints and motor switching nets
C8,C10,C12,C15 | 4 | 100 pF | Gate network | Ceramic C0G/NP0 | THT | Radial disc; pitch TBD | 50
C9,C11,C13,C14 | 4 | 1 nF | Motor snubbers | Pulse-rated polypropylene film | THT | Radial film; pitch TBD | 160 |  |  |  | 160 V provisional; check measured transient and pulse rating
C16,C18,C20,C22 | 4 | 22 uF | Channel bus | Aluminium electrolytic; ripple/ESR specified | THT | Radial; size and pitch TBD | 100
C17,C19,C21,C23 | 4 | 100 nF | Channel bus | Ceramic X7R; DC bias checked | THT | Radial disc; pitch TBD | 100
C24,C27-C29 | 4 | 1 nF | Buffer output filter | Ceramic C0G/NP0 | THT | Radial disc; pitch TBD | 50 |  |  |  | Only buffer supply capacitors C34/C35 are SMD
C25 | 1 | 100 uF | 5 V input | Aluminium electrolytic | THT | Radial; size and pitch TBD | 16
C26 | 1 | 100 nF | 5 V input | Ceramic X7R | THT | Radial disc; pitch TBD | 25
C34 | 1 | 100 nF | U1 local 5 V decoupling | Ceramic X7R | SMD | 0805 candidate; verify PCB | 25 |  |  |  | One of the two SMD capacitors
C35 | 1 | 1 uF | U1 local 5 V decoupling | Ceramic X7R; DC bias checked | SMD | 0805/1206 candidate; verify PCB | 25 |  |  |  | One of the two SMD capacitors
D1-D4 | 4 | 15SQ100 | Per-channel freewheel diode | Schottky, 100 V / 15 A nominal; thermal check | THT | R-6 axial; verify exact vendor |  |  |  |  | Datasheet link in screenshot points to unrelated 1N5817
D5 | 1 | 15SQ100 | Series input polarity diode | Schottky, 100 V / 15 A nominal; thermal check at 12 A | THT | R-6 axial; verify exact vendor |  |  |  |  | Critical thermal review of common 12 A path
D6 | 1 | 1.5KE43A | Supply TVS | Unidirectional TVS; verify polarity and surge energy | THT | DO-201 axial candidate; confirm vendor |  |  |  |  | Check clamp voltage against all bus parts
D7-D10 | 4 | 1N4148 | Gate clamp network | Small-signal switching diode | THT | DO-35 axial |  |  |  |  | Check orientation and forward-current pulses
F1-F4 | 4 | MF-R500 5A PTC | Per-channel resettable protection | PTC hold/trip current at operating temperature | THT | Radial PTC; pitch TBD |  |  |  |  | Verify I_hold at 50 C for 3 A and startup trip behavior
J1 | 1 | Power Terminal | Pump supply input | Terminal block; >=12 A continuous plus margin | THT | Pitch and footprint TBD |  |  |  |  | Check total current and cable gauge
J2 | 1 | PWM Terminal | Logic supply and 4 PWM inputs | Terminal block; pinout and pitch TBD | THT | Pitch and footprint TBD
J3 | 1 | Pumps Terminal | Four motor outputs | Terminal block; >=3 A each plus margin | THT | Pitch and footprint TBD |  |  |  |  | Check each contact rating
Q1-Q4 | 4 | IRLZ44N | Four switching MOSFETs | Logic-level N-channel; hot R_DS(on)/SOA check | THT | TO-220-3; verify PCB orientation |  |  |  |  | Confirm pin mapping and net topology before power testing
R5-R8 | 4 | 10 kohm | Gate pull-down | Resistor; tolerance TBD | THT | Axial; pitch TBD |  | 0,25 |  |  | Power rating provisional
R9-R12 | 4 | 220 ohm | Snubber resistor | Pulse-rated resistor | THT | Axial; pitch TBD |  | 0,5 |  |  | Schematic shows 220 ohm / 0.5 W, not 22 ohm; verify pulse energy
R13-R16 | 4 | 100 ohm | Gate series resistor | Resistor; pulse behavior check | THT | Axial; pitch TBD |  | 0,25 |  |  | Power rating provisional
R17-R20 | 4 | 100 kohm | PWM input pull-down | Resistor | THT | Axial; pitch TBD |  | 0,25 |  |  | Power rating provisional
R21-R24 | 4 | 1 kohm | PWM input series resistor | Resistor | THT | Axial; pitch TBD |  | 0,25 |  |  | Power rating provisional
U1 | 1 | 74AHCT125 | Quad logic buffer | 3.3 V compatible input at 5 V supply; exact P/N TBD | SMD | SOIC-14 candidate; verify PCB |  |  |  |  | Screenshot says 74AHCT125; verify BOM and actual IC marking

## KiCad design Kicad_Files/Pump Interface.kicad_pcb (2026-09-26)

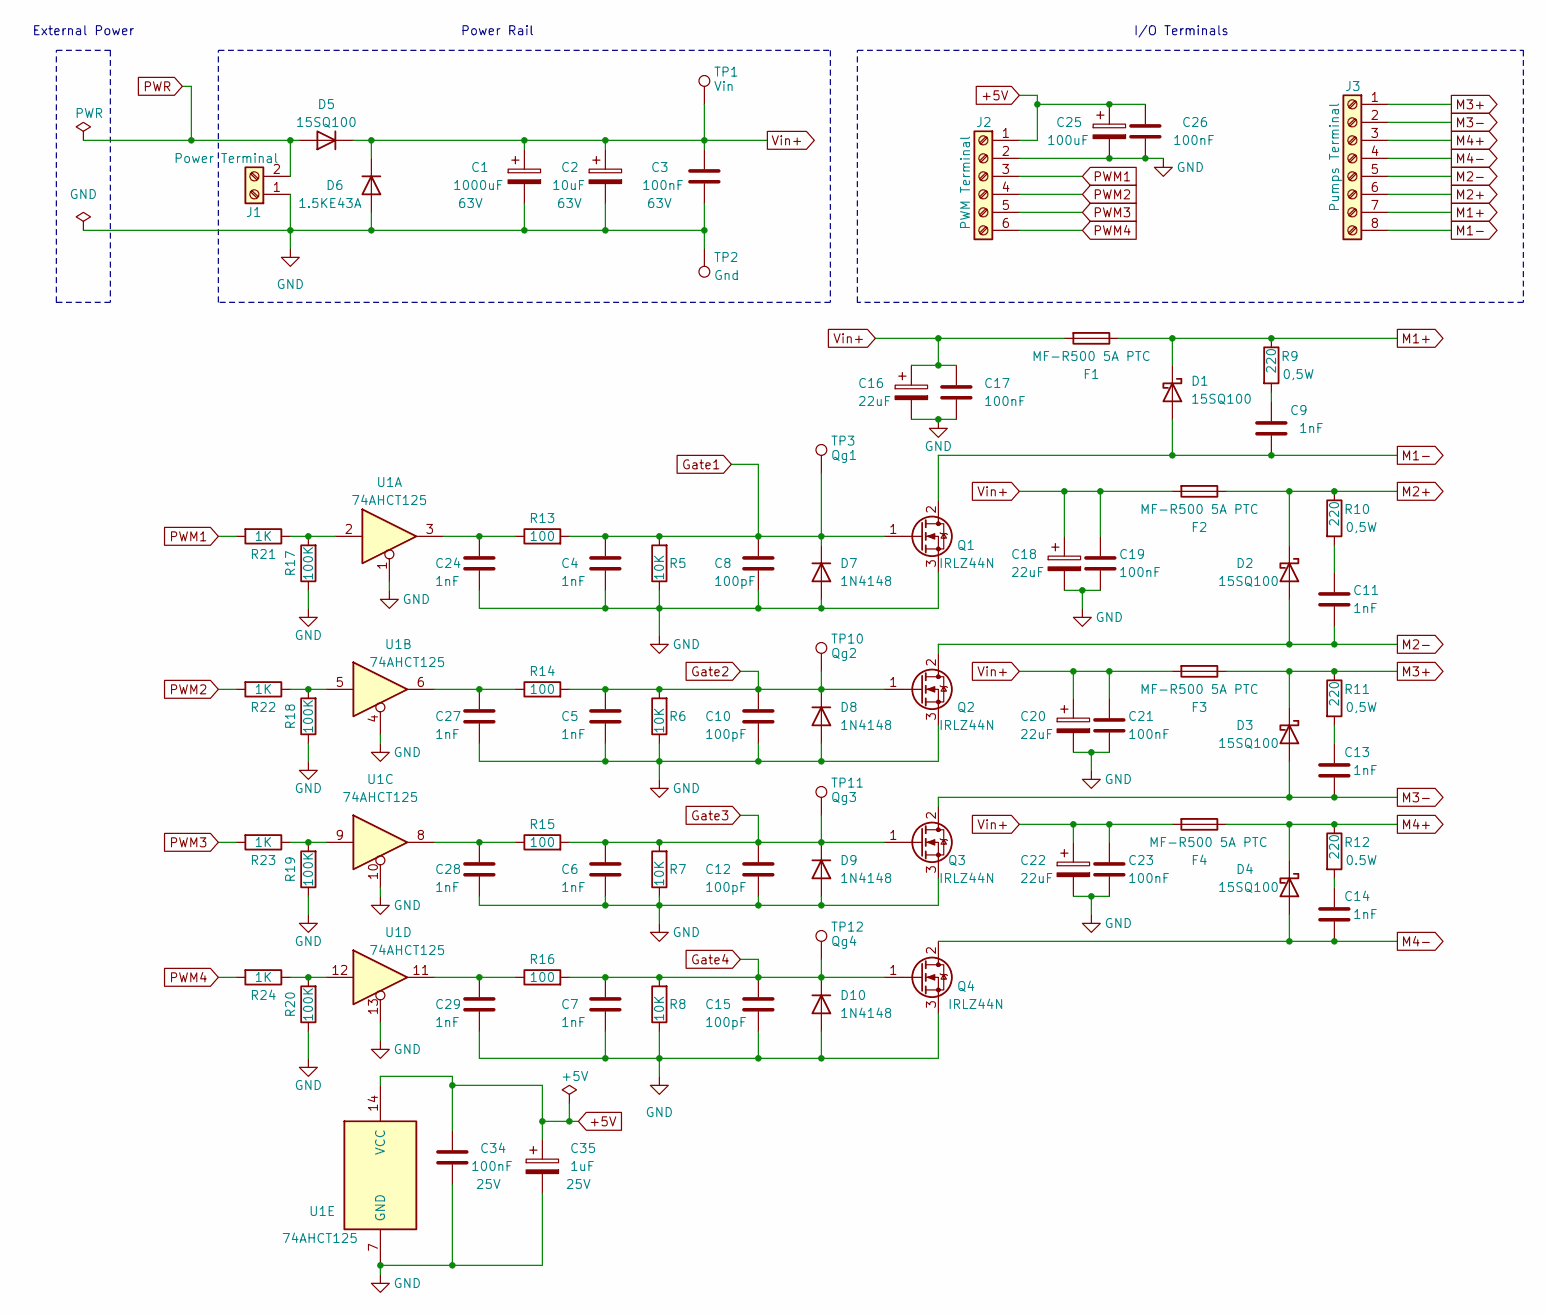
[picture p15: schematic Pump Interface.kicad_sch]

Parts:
C1: 1000uF; CP_Radial_D12.5mm_P5.00mm
C2: 10uF; CP_Radial_D6.3mm_P2.50mm
C3, C17, C19, C21, C23, C26: 100nF; C_Disc_D5.0mm_W2.5mm_P5.00mm
C4, C5, C6, C7, C24, C27, C28, C29: 1nF; C_Disc_D5.0mm_W2.5mm_P5.00mm
C8, C10, C12, C15: 100pF; C_Disc_D3.4mm_W2.1mm_P2.50mm
C9, C11, C13, C14: 1nF; C_Rect_L7.2mm_W2.5mm_P5.00mm_FKS2_FKP2_MKS2_MKP2
C16, C18, C20, C22: 22uF; CP_Radial_D6.3mm_P2.50mm
C25: 100uF; CP_Radial_D6.3mm_P2.50mm
C34: 100nF; C_0805_2012Metric
C35: 1uF; C_0805_2012Metric
D1, D2, D3, D4, D5: 15SQ100; D_DO-201AD_P15.24mm_Horizontal
D6: 1.5KE43A; D_DO-201AD_P15.24mm_Horizontal
D7, D8, D9, D10: 1N4148; D_DO-35_SOD27_P7.62mm_Horizontal
F1, F2, F3, F4: MF-R500 5A PTC; Fuse_Littelfuse-LVR100
J1: Power Terminal; TerminalBlock_Phoenix_MKDS-1,5-2-5.08_1x02_P5.08mm_Horizont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
J2: PWM Terminal; TerminalBlock_WAGO_233-506_2x06_P2.54mm
J3: Pumps Terminal; TerminalBlock_Phoenix_MKDS-1,5-8-5.08_1x08_P5.08mm_Horizont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
Q1, Q2, Q3, Q4: IRLZ44N; TO-220-3_Vertical
R5, R6, R7, R8: 10K; R_Axial_DIN0207_L6.3mm_D2.5mm_P10.16mm_Horizontal
R9, R10, R11, R12: 220; R_Axial_DIN0411_L9.9mm_D3.6mm_P12.70mm_Horizontal
R13, R14, R15, R16: 100; R_Axial_DIN0207_L6.3mm_D2.5mm_P10.16mm_Horizontal
R17, R18, R19, R20: 100K; R_Axial_DIN0207_L6.3mm_D2.5mm_P10.16mm_Horizontal
R21, R22, R23, R24: 1K; R_Axial_DIN0207_L6.3mm_D2.5mm_P10.16mm_Horizontal
TP1: Vin; TestPoint_Pad_1.5x1.5mm
TP2: Gnd; TestPoint_Pad_1.5x1.5mm
TP3: Qg1; TestPoint_Pad_1.5x1.5mm
TP10: Qg2; TestPoint_Pad_1.5x1.5mm
TP11: Qg3; TestPoint_Pad_1.5x1.5mm
TP12: Qg4; TestPoint_Pad_1.5x1.5mm
U1: 74AHCT125; SOIC-14_3.9x8.7mm_P1.27mm

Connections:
+5V: C25.1, C26.2, C34.2, C35.1, J2.1, U1.14 (VCC)
GND: C1.2, C2.2, C3.1, C4.1, C5.1, C6.1, C7.1, C8.1, C10.1, C12.1, C15.1, C16.2, C17.2, C18.2, C19.2, C20.2, C21.2, C22.2, C23.2, C24.1, C25.2, C26.1, C27.1, C28.1, C29.1, C34.1, C35.2, D6.2 (A), D7.2 (A), D8.2 (A), D9.2 (A), D10.2 (A), J1.1, J2.2, Q1.3 (S), Q2.3 (S), Q3.3 (S), Q4.3 (S), R5.1, R6.1, R7.1, R8.1, R17.1, R18.1, R19.1, R20.1, TP2.1 (1_1), U1.1, U1.4, U1.7 (GND), U1.10, U1.13
Gate1: C4.2, C8.2, D7.1 (K), Q1.1 (G), R5.2, R13.2, TP3.1 (1_1)
Gate2: C5.2, C10.2, D8.1 (K), Q2.1 (G), R6.2, R14.2, TP10.1 (1_1)
Gate3: C6.2, C12.2, D9.1 (K), Q3.1 (G), R7.2, R15.2, TP11.1 (1_1)
Gate4: C7.2, C15.2, D10.1 (K), Q4.1 (G), R8.2, R16.2, TP12.1 (1_1)
M1+: D1.1 (K), F1.1, J3.7, R9.1
M1-: C9.2, D1.2 (A), J3.8, Q1.2 (D)
M2+: D2.1 (K), F2.1, J3.6, R10.1
M2-: C11.2, D2.2 (A), J3.5, Q2.2 (D)
M3+: D3.1 (K), F3.1, J3.1, R11.1
M3-: C13.2, D3.2 (A), J3.2, Q3.2 (D)
M4+: D4.1 (K), F4.1, J3.3, R12.1
M4-: C14.2, D4.2 (A), J3.4, Q4.2 (D)
unnamed: C9.1, R9.2
unnamed: C11.1, R10.2
unnamed: C13.1, R11.2
unnamed: C14.1, R12.2
unnamed: C24.2, R13.1, U1.3
unnamed: C27.2, R14.1, U1.6
unnamed: C28.2, R15.1, U1.8
unnamed: C29.2, R16.1, U1.11
unnamed: R17.2, R21.1, U1.2
unnamed: R18.2, R22.1, U1.5
unnamed: R19.2, R23.1, U1.9
unnamed: R20.2, R24.1, U1.12
PWM1: J2.3, R21.2
PWM2: J2.4, R22.2
PWM3: J2.5, R23.2
PWM4: J2.6, R24.2
PWR: D5.2 (A), J1.2
Vin+: C1.1, C2.1, C3.2, C16.1, C17.1, C18.1, C19.1, C20.1, C21.1, C22.1, C23.1, D5.1 (K), D6.1 (K), F1.2, F2.2, F3.2, F4.2, TP1.1 (1_1)

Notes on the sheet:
I/O Terminals
External Power
Power Rail

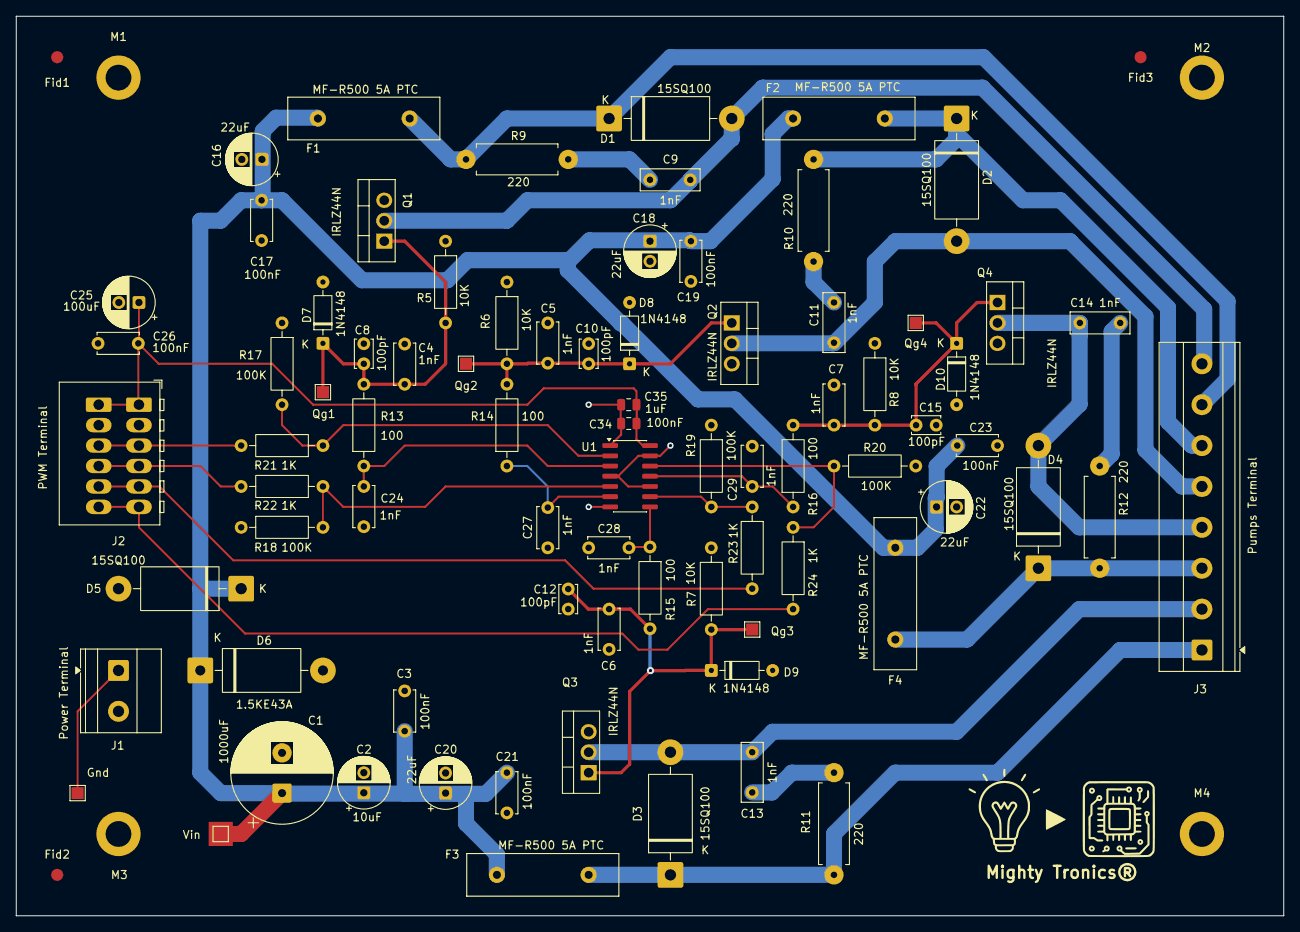
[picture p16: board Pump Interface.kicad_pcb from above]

Board: 4 copper layers, 157.5 x 111.8 mm, 87 parts (0 on the bottom side), 32 nets.

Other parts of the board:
Fid1, Fid2, Fid3: Fiducial_1.5mm_Mask3mm
M1, M2, M3, M4: MountingHole_3.2mm_M3_ISO14580_Pad
Mighty Tronics®: LOGO; Logo-MT-PCB
